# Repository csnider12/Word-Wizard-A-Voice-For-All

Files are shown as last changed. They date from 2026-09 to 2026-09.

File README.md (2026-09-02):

# 🪄 Word Wizard — A Voice For All

**A portable, NFC-based AAC (Augmentative and Alternative Communication) device that gives non-verbal individuals a fast, low-cost, and customizable way to communicate.**

> "Non-verbal individuals often rely on communication tools that are very limited and difficult to customize, as users often have different needs. Educators would benefit from a device that converts physical input to verbal communication that is portable and customizable."

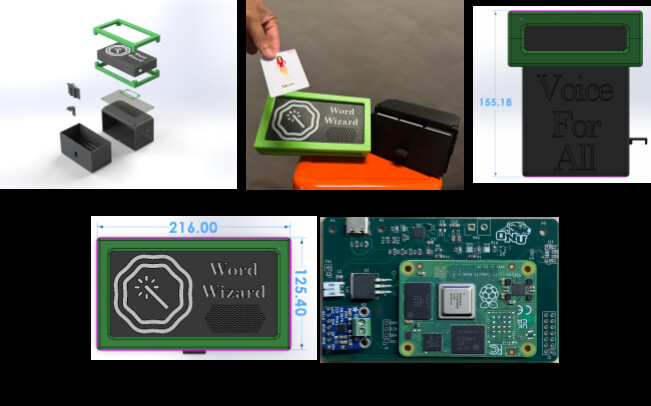
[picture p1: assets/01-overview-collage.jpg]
Word Wizard overview: CAD assembly, device in use, and internal electronics


---

## Table of Contents

- [Overview](#overview)
- [Features](#features)
- [How It Works](#how-it-works)
- [Hardware](#hardware)
- [Electronics & Firmware](#electronics--firmware)
- [Engineering Deep Dive: The PCB Fault](#engineering-deep-dive-the-pcb-fault)
- [Testing: Speaker Grille Optimization](#testing-speaker-grille-optimization)
- [Bill of Materials](#bill-of-materials)
- [Repo Structure](#repo-structure)
- [Design Documentation](#design-documentation)
- [Future Work](#future-work)
- [Broader Impacts](#broader-impacts)
- [Team](#team)
- [Acknowledgments](#acknowledgments)

---

## Overview

Word Wizard is a semester-long engineering project built to give non-verbal students, educators, and caregivers a simple, durable, and affordable alternative to expensive tablet-based AAC systems. A user taps a color-coded NFC communication card on the device, and Word Wizard speaks the corresponding word or phrase aloud through an onboard text-to-speech (TTS) engine.

The device is built around a **Raspberry Pi Compute Module 4** on a custom-designed PCB, an **NFC reader** for card input, a **Piper TTS engine** for multilingual speech output, and a fully 3D-printed enclosure with an integrated card storage drawer.

## Features

-  **NFC-based input** — tap a card, hear a word. No menus, no screens, no complex UI.
-  **Fitzgerald Key color coding** — cards are grouped by grammatical category (questions, actions, social words, people) using a widely recognized AAC standard.
-  **Multilingual TTS** — powered by the [Piper](https://github.com/rhasspy/piper) TTS engine, supporting multiple languages and dialects.
-  **USB-C rechargeable** — ≥30 Wh battery, no proprietary cables or disposable batteries.
-  **Fully customizable vocabulary** — any NFC-writable smartphone can reprogram a card in seconds.
-  **Durable, drop-tested enclosure** — TPU bumper rated for drops from ~3 ft onto hard flooring.
-  **Integrated card storage** — drawer system holds 40+ color-coded cards.
-  **Low-cost alternative** — significantly cheaper than tablet-based AAC solutions, and scalable for classroom/bulk deployment.

## How It Works

1. A teacher or parent programs an NFC card with a word or phrase using any NFC-write-capable smartphone.
2. The user taps the card on the device's NFC reader (marked by the wand logo).
3. A PN532 NFC reader (I2C) on the custom PCB reads the NDEF text record off the card.
4. The Raspberry Pi Compute Module 4 parses the NFC payload and passes it to the Piper TTS engine.
5. Audio is output through a Class-D mono amplifier and speaker, tuned to 60–65 dB (normal speech volume).

## Hardware

| Spec | Detail |
|---|---|
| Compute | Raspberry Pi Compute Module 4 |
| Input | PN532 NFC reader (I2C) |
| Audio | MAX98357A Class-D I2S amplifier + speaker |
| Power | 2S Li-Ion pack, BQ25886 charge management, USB-C input |
| Enclosure | PLA (case, drawer), TPU (bumper, gasket), cast acrylic (lid) |
| Manufacturing | FDM 3D printing (BambuLab A1) |
| Dimensions | 216.0 × 125.4 × 162.2 mm |
| Total weight | ~951 g |
| Battery life | ≥30 Wh |

The enclosure was fully modeled in SolidWorks — see [`design/`](design/) for CAD drawings of the case, drawer/slider assembly, and TPU bumpers, including standoffs for the PCB, speaker grille, charging port, switch port, and NFC reader slot.

## Electronics & Firmware

The custom PCB (`Word Wizard PCB`, designed in KiCad) integrates:

- **CM4 IO Board** — carrier board for the Compute Module 4
- **Power Management** — BQ25886 Li-Ion charger, 5V/5A LDO regulation, power-good and charge-status LEDs, USB-C PD-only input
- **High-Speed I/O** — USB OTG (micro-USB, for CM4 programming) with ESD protection
- **GPIO / DAC** — I2C to the PN532 NFC reader, PCM5122 I2S DAC feeding a MAX98357A audio amplifier

Firmware (C, see [`firmware/`](firmware/)) reads NDEF Text records off NTAG21x cards over I2C using [`pn532-lib`](https://github.com/soonuse/pn532-lib), parses the TLV/NDEF structure, and forwards the decoded text to the TTS pipeline.

```
Wiring (I2C, default):
  PN532 SDA -> RPi GPIO 2 (Pin 3)
  PN532 SCL -> RPi GPIO 3 (Pin 5)
  PN532 VCC -> 3.3V or 5V
  PN532 GND -> GND
```

## Problems: The PCB Fault

One of the most time-consuming parts of the project was tracking down an intermittent fault on the custom PCB. Code and hardware that worked fine on a jumper-wired development board began failing after being transferred to the custom board — the device would boot normally, then enter a boot loop roughly 20–30 seconds after a card was read.

**Diagnosis process:**

1. Ruled out power-supply issues by isolating each board on its own supply.
2. Put the PN532's I2C bus on an oscilloscope. The data line topped out at 3.1V instead of a full 3.3V logic high.

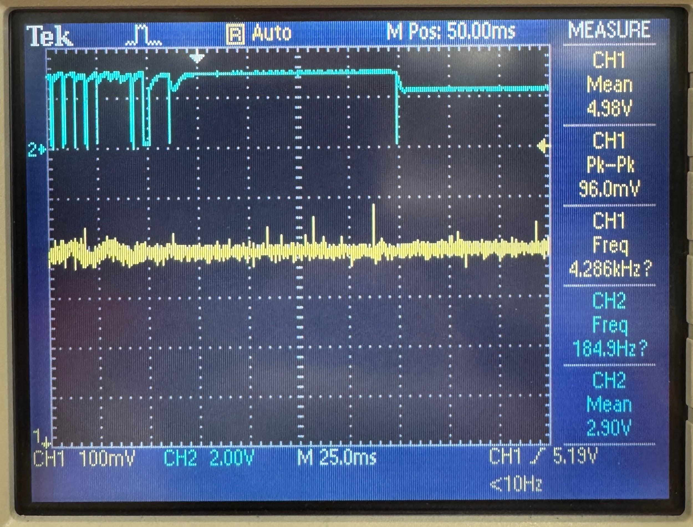
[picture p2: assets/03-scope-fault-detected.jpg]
Oscilloscope trace showing degraded I2C logic level
    

3. After ~20–30 seconds, the data line collapsed to 2.31V — indicating the board was hitting a thermal fail-safe and powering itself down.

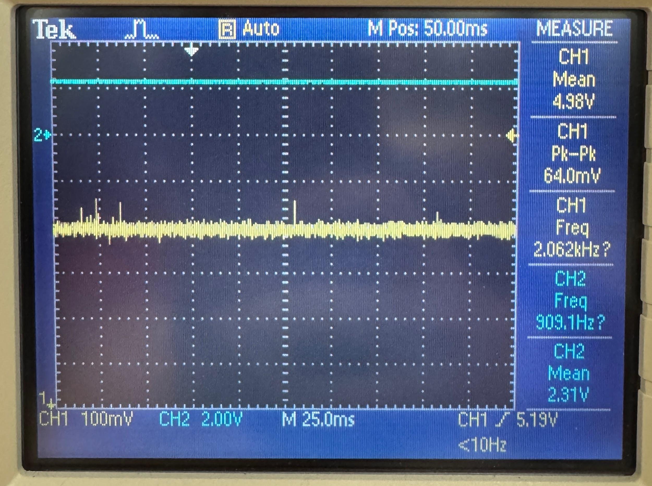
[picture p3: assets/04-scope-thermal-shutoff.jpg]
Oscilloscope trace showing CM4 thermal shutoff
    

4. Root cause: the CM4's **GPIO_VREF** pin — which must be hard-tied to 1.8V or 3.3V to set GPIO logic level — had been left floating on the custom board, settling at ~2.3V. External 3.3V pull-up resistors (added for the PN532) were fighting that incorrect reference, creating an extra thermal load that eventually tripped the CM4's thermal protection.
5. **Fix:** manually rewired GPIO_VREF directly to 3.3V using 39 AWG wire under a microscope — a delicate hand-soldering job on a Hirose board-to-board connector.

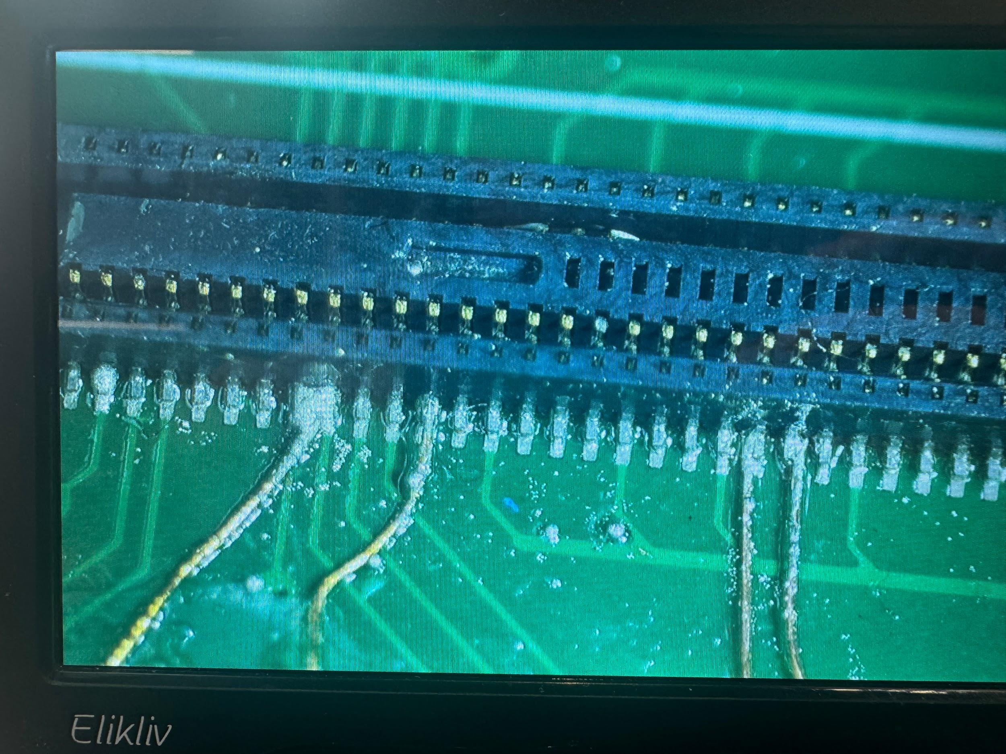
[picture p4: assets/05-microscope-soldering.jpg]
Microscope view of manual rework on the Hirose connector pins
    

6. Verified the fix back on the oscilloscope: clean rising/falling edges on both I2C lines, comfortably past the logic thresholds.

This was the single biggest lesson of the build: one unconnected reference pin caused hours of debugging, a reminder of how much value there is in double-checking datasheets and having a second set of eyes on a schematic before fabrication.

## Testing: Speaker Grille Optimization

To find the best trade-off between sound clarity and dust/debris resistance, the team 3D-printed six speaker grilles with hole diameters from 1.5mm to 4.0mm and measured sound pressure level (dB) at a fixed distance for three test phrases ("Why," "Please," "Stop").

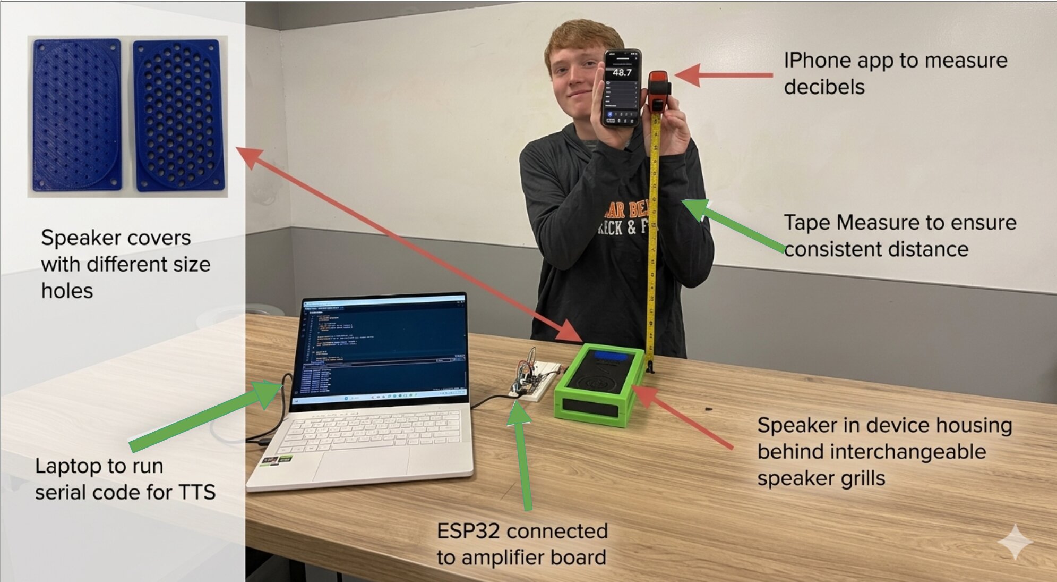
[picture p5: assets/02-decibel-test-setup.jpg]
Decibel testing setup with speaker, ESP32, amplifier, and sound level meter


**Result:** the **2.5mm hole diameter** produced the best average sound output (71.7 dB vs. 68.5 dB uncovered) while still offering meaningfully better debris resistance than larger holes. Full raw data and the test protocol are in [`testing/decibel-test-results.md`](testing/decibel-test-results.md).

## Bill of Materials

Full sourced BOM with vendor links and pricing is in [`bom/budget-tracker.md`](bom/budget-tracker.md). Total project spend: **~$205** (largely CM4/board, NFC reader, speaker, amp, and passives).

## Repo Structure

```
word-wizard/
├── README.md
├── firmware/            # NFC read + NDEF parsing (C)
├── hardware/            # KiCad schematics/PCB, connector notes
├── design/              # SolidWorks/CAD drawings, drawer & bumper parts
├── testing/             # Speaker grille dB test protocol + raw results
├── bom/                 # Sourced bill of materials
├── docs/                # Educator user manual, problem framing, broader impacts
└── assets/              # Photos and diagrams used in this README
```

> **Note:** this repo currently hosts the project write-up, CAD reference drawings, firmware, and PCB schematics consolidated from the team's final report. If you're setting this up as a fresh GitHub repo, drop your actual `.kicad_pro`/`.kicad_sch`, `.SLDPRT`/`.SLDASM`, and source files into the folders above alongside this README.

## Design Documentation

- [Educator Reference Manual](docs/user-manual.md) — setup, daily operation, charging, cleaning, troubleshooting
- [Problem Framing](docs/problem-framing.md) — stakeholders, research questions, assumptions, evaluation metrics
- [Broader Impacts](docs/broader-impacts.md) — People / Planet / Profit analysis with tradeoffs

## Future Work

- Move card access from a bottom drawer to a top-loading slot to reduce operating complexity for the primary user
- Merge the device and card-storage system into a single piece for easier management by teachers/parents
- Injection-molded silicone bumper (removable, phone-case style) instead of 3D-printed TPU, for easier cleaning and to escape FDM print constraints
- Switch the audio path from I2S to **SPI** to improve software/response speed
- Consolidate the electronics footprint to reduce overall device size and material use
- Standardize on common screws for all hardware to improve end-of-life disassembly and recyclability (balanced against tamper risk)

## Broader Impacts

| Category | Benefits | Risks / Tradeoffs |
|---|---|---|
| **People** | Shock-absorbent TPU bumper, USB-C (no proprietary cables), low-cognitive-load NFC tap input | Accessible screws are also a tamper/safety risk for young users; drawer adds a second part to manage |
| **Global/Cultural** | Fitzgerald Key is a recognized AAC standard; Piper TTS supports multiple languages/dialects | Color coding may not translate across cultures; NFC programming requires a smartphone |
| **Planet** | No laminate/print waste from reprogramming; modular hardware extends device life; rechargeable battery; recyclable ABS/TPU | PCB components are non-biodegradable; current manufacturing is energy-intensive |
| **Profit** | Lower cost than tablet AAC alternatives; scalable/modular for schools; costs drop with bulk orders | Long device lifespan reduces repeat business; SPI migration would add R&D cost |

Full stakeholder analysis and research log in [`docs/problem-framing.md`](docs/problem-framing.md).

## Team

Built by **Team 5**, Ohio Northern University — Foundations of Design II, 2026.

| Name | Focus Areas |
|---|---|
| Ethan D'Souza | Documentation, testing, broader impacts, electronics selection |
| Logan Frazer | CAD, NFC card programming, drawing annotation |
| Aiden McManis | Poster, scheduling/Gantt, presentation, drawer/slider design |
| Owen Willoby | Poster design, budget tracking, troubleshooting |
| Jeremiah Koenig | Final assembly, PCB population, presentation |
| Collin Snider | PCB design, diagnosis & rework, wiring/assembly |

## Acknowledgments

- Christina Teevan, Executive Director, Ashland Special Needs Ministry — early-stage user research
- Ohio Northern University Foundations of Design II course staff
- AI tools (Claude, Gemini, ChatGPT, GPAI) were used for problem framing, text refinement, and firmware assistance — see [`docs/ai-disclosure.md`](docs/ai-disclosure.md)

## License

Released under the [MIT License](LICENSE) — feel free to fork, build on, or adapt this project. Swap in a different license if your team/school has different preferences.

---

*Originally submitted as a final capstone report. Ported to GitHub as a project reference and portfolio piece.*

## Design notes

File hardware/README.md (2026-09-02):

# Hardware — Word Wizard PCB

Custom carrier/IO board for the Raspberry Pi Compute Module 4, designed in **KiCad 9.0.4**.

| Sheet | Contents |
|---|---|
| `CM4 IO Board` (top) | CM4 module footprint, mounting holes, sheet references |
| `CM4_GPIO` | 5x GPIO breakout, I2C (NFC reader), I2S audio, boot jumpers |
| `CM4_HighSpeed` | Micro-USB (CM4 programming) with ESD protection, USB OTG |
| `Power Management` | BQ25886 Li-Ion charger, USB-C power-only input, 5V/5A LDO, status LEDs |
| `DAC` (under CM4_GPIO) | PCM5122 I2S DAC → MAX98357A Class-D audio amplifier |

## Key design notes

- **Power path:** USB-C (power only) → BQ25886 charge management → 2S Li-Ion pack → LM1084-5.0 LDO for a clean 5V rail to electronics.
  - R2 (8kΩ) sets ~2.2A charge current (~0.4C for the battery)
  - R3 (150kΩ) sets 8.4V charging voltage
  - R4 (383Ω) sets ~2.9A max input current
  - R7/R9 (5.1kΩ on CC pins) configure 5V/3A charge negotiation over USB-C
- **NFC reader:** PN532, I2C interface, connected via the GPIO breakout sheet.
- **Audio:** PCM5122 I2S DAC feeding a MAX98357A mono Class-D amplifier (gain set by R1: 0Ω = left channel / 9dB gain).
- **Programming:** Micro-USB OTG port for flashing the CM4's eMMC, protected by a TPD4EUSB30 ESD array.

## ⚠️ Known erratum — GPIO_VREF must be tied, not left floating

On the first board revision, **GPIO_VREF (CM4 pin 78)** was left floating, which averaged to ~2.3V and caused the CM4 to enter a thermal fail-safe shutdown roughly 20–30 seconds after boot (see the [PCB fault deep-dive in the main README](../README.md#engineering-deep-dive-the-pcb-fault)). If you're laying out your own revision of this board, **hard-tie GPIO_VREF directly to 3.3V** in the schematic and layout — don't rely on external pull-ups alone.

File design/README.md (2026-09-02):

# Design — CAD & Mechanical

Above

## Assembly Overview

**Overall dimensions (L×W×H):** 216.00 × 125.40 × 162.18 mm
**Total weight:** ~951 g

| # | Part | Material | Weight (g) | Manufacturing |
|---|---|---|---|---|
| 1 | Drawer Box | PLA | 237 | FDM 3D printed |
| 2 | Drawer | PLA | 302 | FDM 3D printed, ~7h 52m print time |
| 3 | Slider | PLA | 3.55 | FDM 3D printed, ~11 min print time |
| 4 | Slider Guide | PLA | 9.58 | FDM 3D printed, ~23 min print time |
| 5 | Case | PLA | 170 | FDM 3D printed, ~3.75 hr print time (BambuLab A1) |
| 6 | Lid | Cast Acrylic | 118 | — |
| 7 | Speaker Gasket | TPU | 0.47 | FDM 3D printed |
| 8 | Bumper Bottom | TPU | 52.4 | FDM 3D printed, ~2.8 hr print time |
| 9 | Bumper Top | TPU | 58.2 | FDM 3D printed, ~2.9 hr print time |

**Misc. assembly hardware:** 4x M3×5mm screws + inserts, 4x M4×15mm screws + inserts, cyanoacrylate glue.

## Assembly Notes

- Insert the slider first, and lock it in place with the slider guide.
- Secure the speaker gasket between the speaker and casing before screwing the assembly together.
- Screw the acrylic lid to the case.
- Glue bumpers to the edges of the case (×2).
- The case includes 9x standoffs for the PCB, plus cutouts for the speaker grille, switch port, charging port, and NFC reader slot.
- All fillets on TPU bumper parts are 3mm.
- The drawer/slider system uses a gravity latch so the drawer can be lifted without requiring much dexterity — a deliberate accessibility choice for the primary stakeholder (the student/user).

See the [Future Work section of the main README](../README.md#future-work) for planned mechanical revisions (top-loading card access, injection-molded silicone bumper, single-piece device/storage design).

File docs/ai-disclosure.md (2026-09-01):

# Appendix: AI Disclosure

AI was used in problem framing, refining text, and programming the device. AI models used were Claude, Gemini, ChatGPT, and GPAI.

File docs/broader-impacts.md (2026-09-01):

# Appendix: Broader Impacts

| Category | Benefits | Risks and Tradeoffs |
|---|---|---|
| **People — Public Health, Safety & Welfare** | Shock-absorbent TPU bumper reduces injury risk when dropped or thrown. USB-C eliminates the need for proprietary cables. Simple NFC tap input reduces cognitive load for the intended user. | Easy-access screws for repair can be a safety hazard to young/curious individuals. TPU bumper increases overall device footprint. Drawer system requires the device to have two separate parts to manage. |
| **People — Global / Cultural Factors** | Color-coded Fitzgerald Key is a widely recognized AAC standard. The Piper TTS model allows the system to output multiple languages and dialects. | Color coding may not transfer across different cultures. NFC programming requires a smartphone or other proprietary device. |
| **Planet — Environmental** | Programmable cards reduce the need for laminate/print waste. Modular electronic hardware extends device life, reducing waste. Rechargeable battery reduces single-use waste. ABS and TPU are recyclable materials. | Components like the PCB are non-biodegradable. Current manufacturing process is energy-intensive. |
| **Profit — Economic** | Lower cost than tablet-based AAC alternatives. Design is easily scalable and modular for large-quantity school/care-center needs. Electronics are easy to fabricate, and per-unit price drops with bulk orders. | Switching to SPI protocol would require additional R&D man-hours, raising costs. Long product lifespan reduces repeat business unless a compelling updated product is released. |

## Ecodesign Strategies Considered

- **Optimize end-of-life system** by making all hardware components accessible via common screws, increasing ease of disassembly and recyclability — tradeoff: could tempt users to tinker and harm device functionality.
- **Optimize initial lifetime** by reducing the number of soldered-to-connector parts, easing repairability — tradeoff: could reduce reliability if parts get jostled loose during use.
- **Reduce materials** by further consolidating the electronics footprint to shrink the device and reduce material use — tradeoff: could increase electronics complexity and cost.

The team believes there is a viable middle ground across these strategies that balances repairability, reliability, and cost.

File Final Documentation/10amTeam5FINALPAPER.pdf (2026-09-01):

# Word Wizard

“Non-verbal individuals often rely on communication tools that are very limited and difficult to

customize, as users often have different needs. Educators would benefit from a device that

converts physical input to verbal communication that is portable and customizable.”

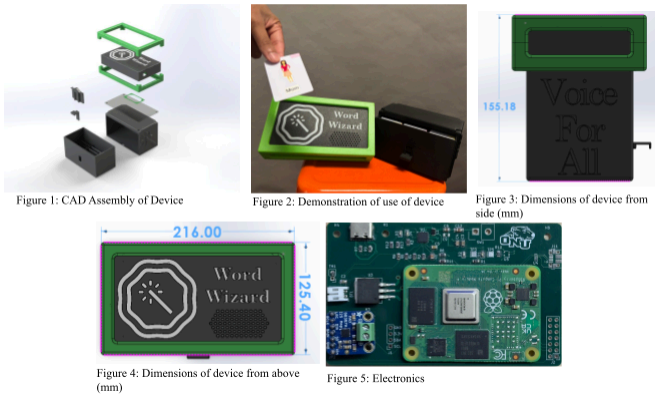
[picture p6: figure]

# Next Steps

While this design was extensively researched and revised over the course of the semester, our team recognized several features that could still be improved given we had more time. While our current storage system is innovative and easy to navigate, we believe the system could be improved by making the cards accessible from the top of the box rather than a drawer system to lower the complexity of operating the system for our primary stakeholder, the user. We also presume that making the device and the card system one piece would improve the manageability of Word Wizard for teachers and parents. Additionally we hope that in the future the bumper could be injection molded silicone so that we are not limited to 3-D printing capabilities. This is so we can make the bumper removable, similar to a phone case to improve the cleanability of the device. Finally we would implement an SPI communication protocol rather than the I2S protocol we currently use to optimize software speed for the device. These changes would help us compete in the global market more effectively and provide the best overall product for all stakeholders.

There are many ecodesign strategies we could employ in the further development of our product. We could optimize the end of life system by making all the hardware components accessible by common screws. This is so that we can increase the ease of disassembly and recyclability of the various different components. While this will be good for properly recycling components at end of life, it could tempt users to tinker and harm device functionality. Additionally we could optimize the initial lifetime by reducing the amount of soldered parts to connectors. While this makes repairability easier it could harm the reliability of the product as parts could be jostled loose during use. This is so that electronic parts can be easily swapped out to increase the lifespan of the device. Lastly we could further the reduction of materials by finding ways to further consolidate the footprint of the electronics. This will allow us to shrink the size of the device, reducing the necessary material required to fabricate all related parts. While this could reduce the footprint of the electronics, it could increase the complexity of the electronics further driving up costs. While these ecodesign strategies have pros and cons, we believe that there is a middle ground that makes these aspirations viable.

# Broader Impacts

Table 1: Broader Impacts

| Benefit | Risks and Tradeoffs
People - Public Health, Safety & Welfare | - Utilizing a shock absorbent TPU bumper reduces injury risk when dropped or thrown - USB - C eliminates the need for proprietary application specific cables - Simple NFC tap input reduces cognitive load for the intended user | - Easy to access screws for easy repair can be a a safety hazard to young and curious individuals - TPU bumper increases overall footprint of device - Drawer system requires device to have two separate parts to manage
People - Global / Cultural Factors | - Color coded Fitzgerald Key is a widely recognized AAC standard - utilizing Piper TTS model allows the system to output multiple languages and dialects | - color coding may not transfer across different cultures - NFC programming requires a smartphone or other proprietary device
Planet - Environmental | - programmable reduces need for laminate and print waste - Modular electronic hardware allows for extended life of device, reducing waste - Rechargeable battery reduces single-use waste - ABS and TPU are recyclable materials | - Various electrical components like the PCB are non-biodegradable - Current manufacturing process is very energy intensive
Profit - Economic | - Lower cost than tablet alternative AAC’s - Design is easily scalable and modular to accommodate large quantity needs for schools or care centers - Electronics are easy to fabricate and price gets lower as the bulk of the order increases | - a switch to SPI protocol would require further man-hours driving up our R&D costs - Our product has a long lifespan which will reduce our repeat business unless we come out with an updated more enticing product.

# Appendix 1: Problem Framing

Overview: Problem Framing Documentation For FoD2 Semester Project ‘Word Wizard’

Broader Impacts:
1. People - Inclusion and Accessibility to reduce stigma around disability
2. Planet - Long-lasting and purpose built solution allows for less material waste and power consumption
3. Profit - Lower cost and scalable solution compared to existing assistive technologies

Stakeholders:

Table 2: Stakeholders

| Stakeholder | Impact | Design decision considerations
1 | Student | Usability, Comfort, Reliability | Safer casing, minimal simplistic inputs
2 | Teachers | Integration and Manageability | Small, rechargeable, minimal design, with clear colors for locatability
3 | Administrators | Budget and Policy Compliance | Low-tech design, Cost less than common alternatives (Tablet, or other repurposed smart device)
4 | Parents | Independence and Safety | Soft outer casing, simplistic usability for a wide age range

Research:

Table 3: Preliminary Research

Prompting
Question
Source | Specific information gathered | What will you do with this info?
| DR1
1 | How tall are classroom desks and tables? | [1] 24”-30” | | This data will influence our durability benchmarks.
2 | How can we smooth 3D prints? | [2, 3] | ABS can be smoothed with acetone, TPU can be smoothed with DMSO | Consider solvent smoothing for the surface finish of 3D printed parts

3 | What is the most common consumer charging cable? | [4] | USB Type-C is “Common on modern laptops, smartphones, and game consoles. [It] is the new industry standard.” | We will use a USB-C port for power input
4 | What kind of 3D printing filament is the most durable? | [5] | ABS has a higher impact resistance than both PLA and PETG but it has worse printability. | ABS will be the preferred filament as it is the strongest and we will have to be more careful when printing with it.
5 | Why use NFC tags instead of anything else for Voice recording? | [6] | NFC tags offer an easy, touch-based way to play, record, or update audio, making them highly accessible for tasks like labeling objects for the visually impaired or creating personalized voice messages without using complex menus. | We will use NFC tags for easy use and easy updating
6 | What are the issues with paper communication cards? | Christina Teevan, Ashland Special Needs Ministry Executive Director | The commonly used paper cards are not durable, difficult to organize, and take concentration by both parties to communicate. | We will make a device to combine physical communication cards and text-to-speech communication devices.

DR2

1

What is an
effective dB level
for sufficient
communication
and how will our
enclosure affect
that?

[1]

- Target output at listener: 60-65 dB
- Upper practical range:
65-70 dB (if classroom
noise is higher)

This aligns with:

- Normal speech = 60 dB
- Slightly raised voice =
65–70 dB

Aim for a noise range between 60 -65 Decibels

2

How do educators
currently store,
organize, and
manage
communication
cards in classroom
environments?

[2]

Bins and Binder Pockets -
Educators typically use baseball card organizers to track specific cards, and store larger amounts of cards in small storage bins

Develop a system that blends these two tracking systems. I.e. organized drawer

DR 3

1 | How can we reduce rattling of the speaker when mounted in the casing? | [1] | “When a speaker is mounted behind a cover, the sealing between the speaker and the surface dictate the Sound Pressure Level”[1] Air leaking out the speakers rim | Add a sort of gasket to seal the speaker
2 | How can we further make cards easier to organize? | [2] | - Augmentative and Alternative Communication(AAC) systems [2] - Fitzgerald Key: Assigns colors to differentiate various grammatical categories [2] - Color coded designs require less cognitive load [3] | Color code the cards to better organize and track them

Assumptions:
1. Because classroom desks and tables are typically 24”-30” tall [1], we assume accidental drops from approximately 3 feet onto hard flooring are likely. Therefore, we will design the enclosure to withstand at least a 3 foot drop without functional failure.
2. Because some non-verbal individuals may also experience visual processing challenges, we assume high-contrast visual cues will improve usability. Therefore, we will use contrasting colors and clear iconography to indicate interaction zones.
3. Based on classroom environments where many interactable objects are used simultaneously, we assume communication cards may frequently be misplaced. Therefore, we will research and integrate a dedicated card storage or tethering solution.
4. Based on hygiene practices in schools and therapy settings, we assume the device will require frequent surface cleaning. Therefore, we will select enclosure materials (ABS/TPU/PLA) that tolerate repeated wiping without degradation. It also may be necessary to seal surface pores to decrease bacterial buildup.
5. Because USB-C charging cables are commonly included with consumer electronics [4] and are easily purchasable, we assume that the users will have access to these cables more readily than other types. Therefore, we will include a USB-C port for power input.

Design Specifications:
Table 4: Evaluation Metric
| Evaluation Metric | Qty. to Measure | Units | Objective | Prototype Result
1 | Battery Life | Both | Watt-Hour (Wh) | ≥ 30 Watt-hours | Utilize a rechargeable battery that still accounts for safety
2 | Boot Time | EM | Seconds (s) | minimize | Optimize hardware utilizing a compute module
3 | Response Time | EM | Seconds (s) | minimize | Optimize hardware utilizing a compute module
4 | Sound Level | EM | Decibels (dB) | ≥ 60 | Functionally test different speaker grills for housing.
5 | Portability | EM | grams(g) | minimize | Minimized unnecessary additional cables and hardware to make device as transportable as possible
6. | Variability of Word List | C | # of cards | ≥ 30 | Diversified vocabulary so device can be versatile in many scenarios
7. | Customizability of Word List | EM | # of ways to change each card | maximize | Cards can be changed on a need to need basis very easily through a simple smartphone

# Appendix 2: Test Results

Test Title: Decibel Output Testing for Variable Speaker Holes

Purpose: To determine the best speaker cover to ensure the optimal sound clarity and quality determined by decibel levels.

Equipment:
- Speaker
- Microcontroller
- Amplifier
- Speaker covers (6 covers)
- Sound Level Meter
- Tape Measure
- Means to record data

Variables:

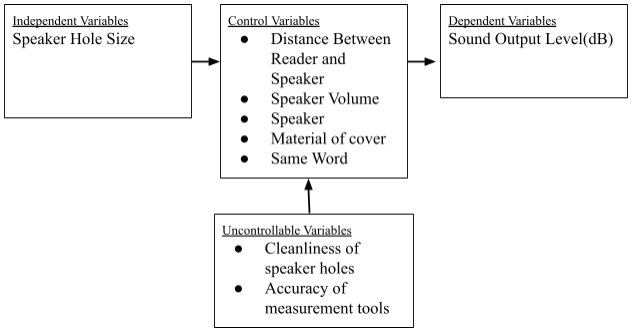
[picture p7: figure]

Experimental Setup:

Figure 6: Setup to test audio loss due to diameter of holes

Figures 7-9: CAD renderings for varying speaker cover hole diameters (1.5mm, 2.5mm, 3.5mm)

Procedure:
1. Gather all materials.
2. Place materials on a table that is cleared and ready for the test.
3. Hook up the speaker to the amplifier + microcontroller apparatus.
4. Cover speaker with speaker cover
5. Hold sound level reader at ear level
a. Speaker should be oriented towards you, still on the table
6. Use the sound level reader to collect data from the speaker output.
7. Output text to speech word from the speaker.
8. Repeat steps 4 through 6, changing / adding the speaker cover of varying hole diameters.
9. Write down results in the data table.
10. Write down any observations collected during the test.

Quantitative Results:
Table 5: Table to collect effective decibels across three tests at different amounts of obstruction

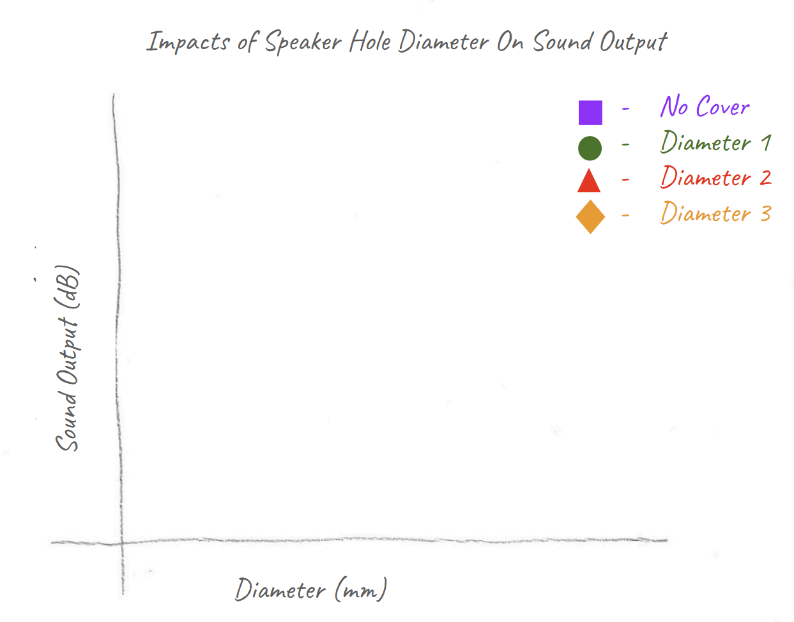
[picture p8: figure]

Figure 10: Scatterchart to compare effective decibels at different diameters of holes

Decibels (dB) | Control (no cover) | Hole Diameters (mm)
D1 | D2 | D3
Run 1
Run 2
Run 3
Average

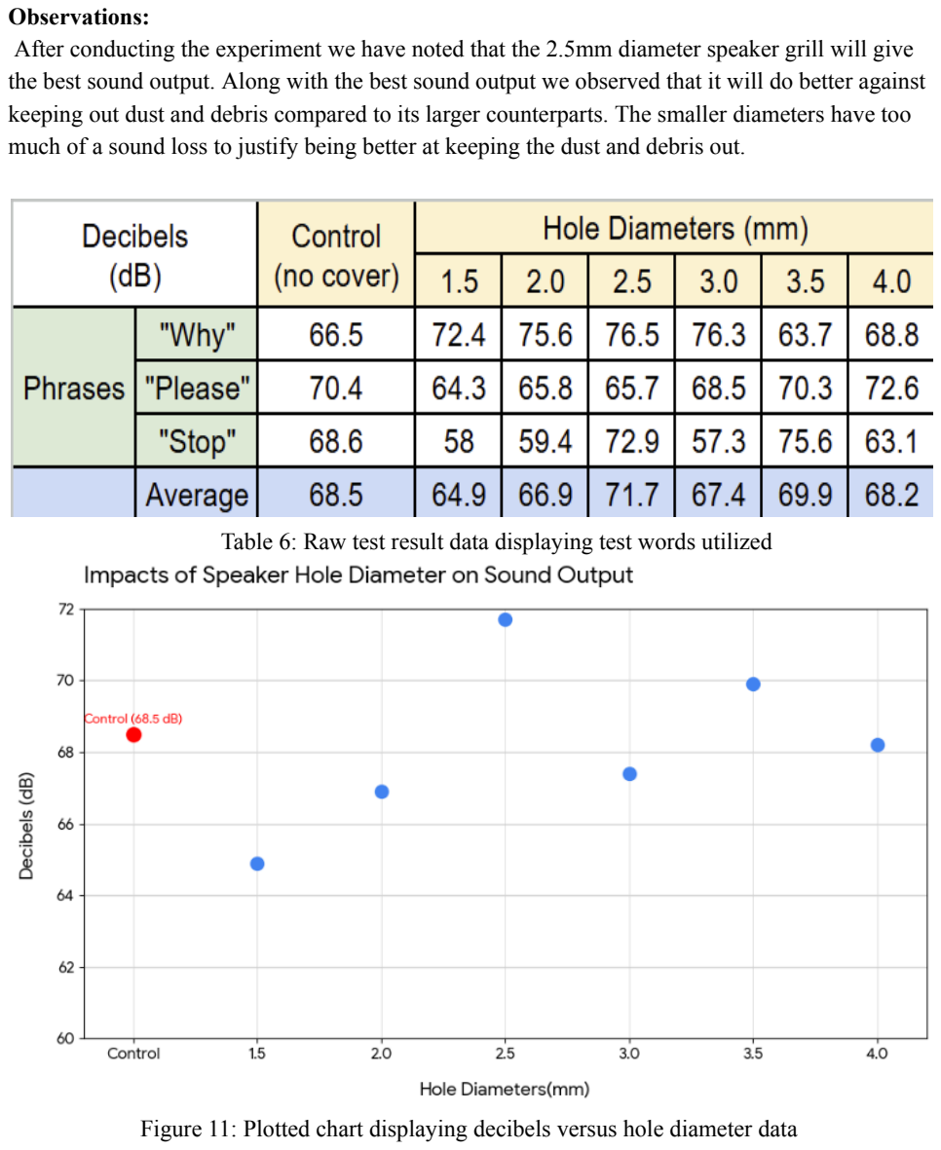
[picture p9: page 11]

Observations:
After conducting the experiment we have noted that the 2.5mm diameter speaker grill will give the best sound output. Along with the best sound output we observed that it will do better against keeping out dust and debris compared to its larger counterparts. The smaller diameters have too much of a sound loss to justify being better at keeping the dust and debris out.

Table 6: Raw test result data displaying test words utilized

Figure 11: Plotted chart displaying decibels versus hole diameter data

Picture:

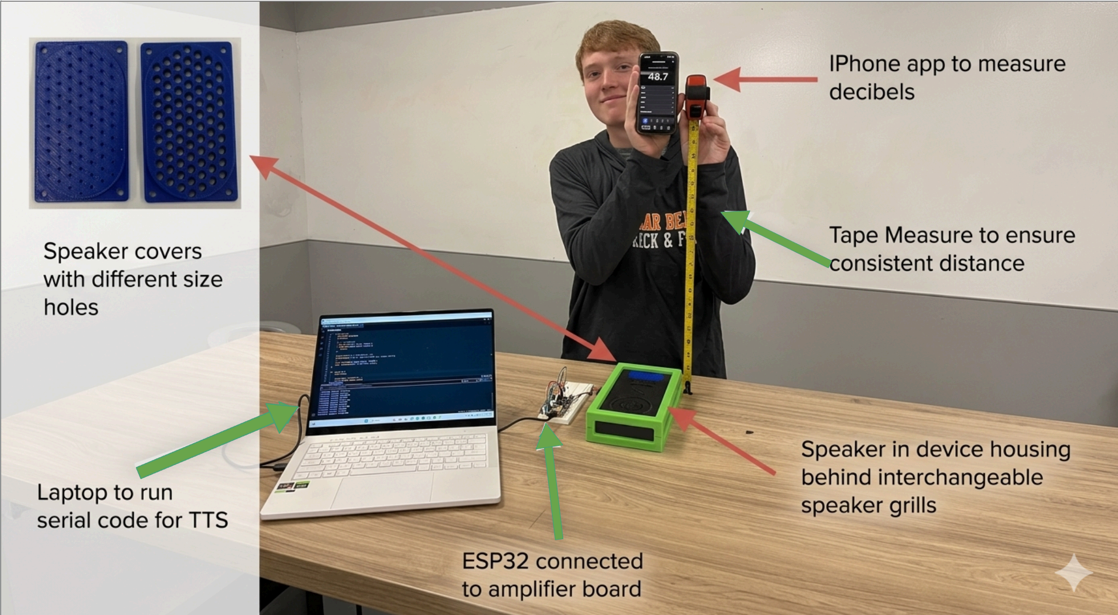
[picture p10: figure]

Conducted by: Ethan D’souza, Owen Willoby, Jeremiah Koenig, Aiden McManis

Date test conducted: 4/9/26

# Appendix 3: Design Details

B | B

2

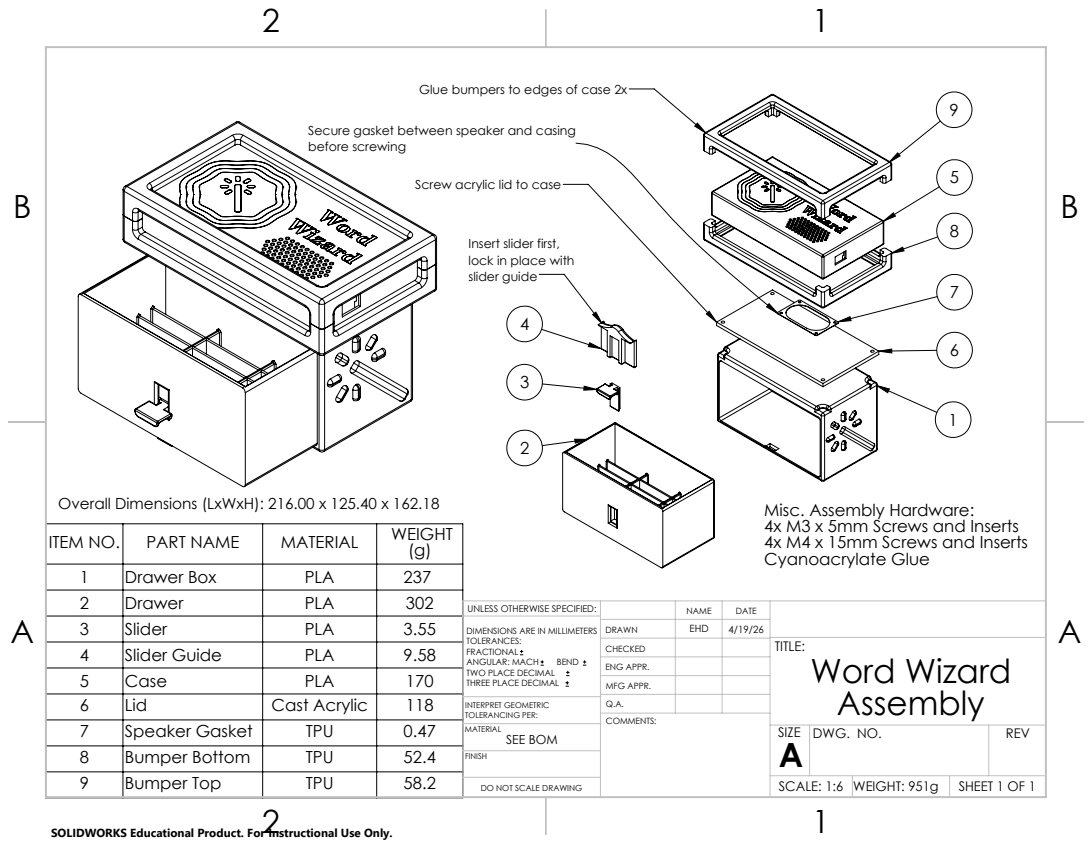
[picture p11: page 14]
SEE BOM; DWG. NO.; REV; SIZE; COMMENTS:; FINISH; MATERIAL

Glue bumpers to edges of case 2x

Secure gasket between speaker and casing
before screwing

Screw acrylic lid to case

Insert slider first,
lock in place with
slider guide

Overall Dimensions (LxWxH): 216.00 x 125.40 x 162.18

Misc. Assembly Hardware:
4x M3 x 5mm Screws and Inserts
4x M4 x 15mm Screws and Inserts
Cyanoacrylate Glue

ITEM NO. | PART NAME | MATERIAL | WEIGHT (g)
1 | Drawer Box | PLA | 237
2 | Drawer | PLA | 302
3 | Slider | PLA | 3.55 | DIMENSIONS ARE IN MILLIMETERS TOLERANCES: FRACTIONAL ANGULAR: MACH BEND TWO PLACE DECIMAL THREE PLACE DECIMAL | DRAWN | EHD | 4/19/26
4 | Slider Guide | PLA | 9.58 | | CHECKED | | | TITLE: Word Wizard Assembly
5 | Case | PLA | 170
6 | Lid | Cast Acrylic | 118 | INTERPRET GEOMETRIC TOLERANCING PER: | Q.A.
7 | Speaker Gasket | TPU | 0.47
8 | Bumper Bottom | TPU | 52.4
9 | Bumper Top | TPU | 58.2

UNLESS OTHERWISE SPECIFIED: | | NAME | DATE

ENG APPR.
MFG APPR.

DO NOT SCALE DRAWING | SCALE: 1:6 | WEIGHT: 951g | SHEET 1 OF 1

SOLIDWORKS Educational Product. For Instructional Use Only.

B | B

2

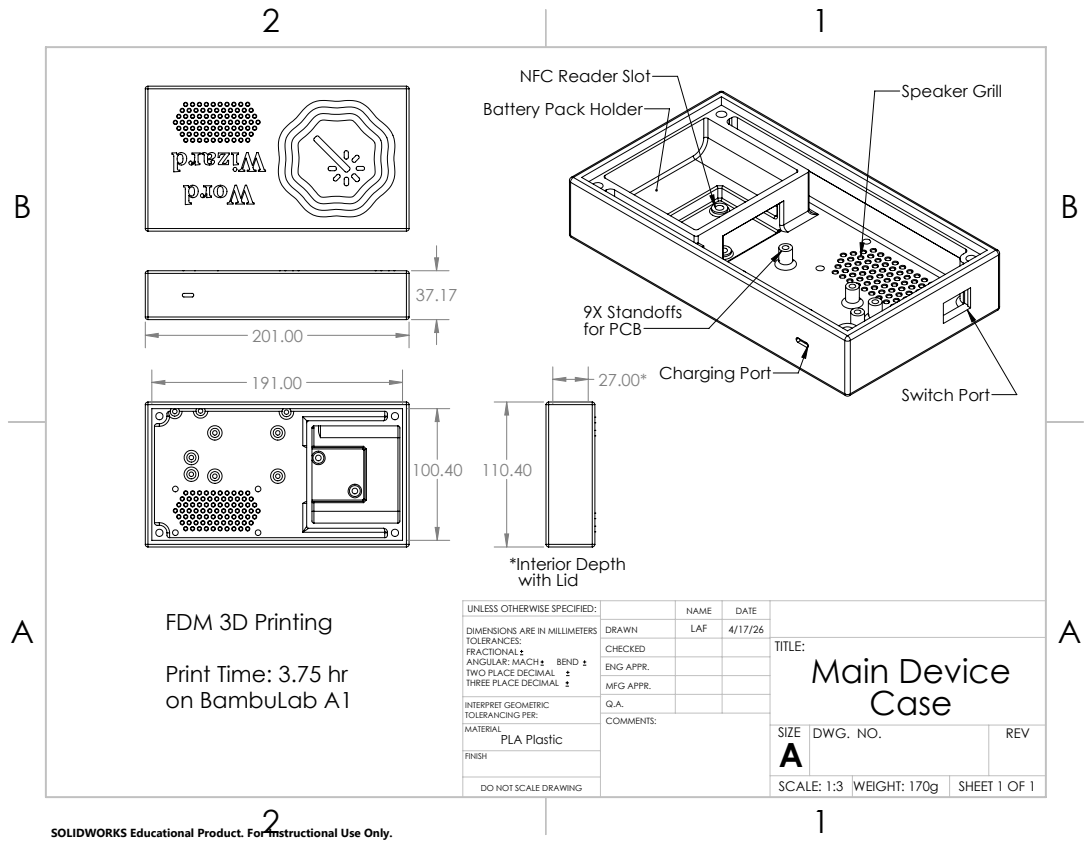
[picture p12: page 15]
9X Standoffs for PCB; Speaker Grill; Switch Port; Charging Port; *Interior Depth with Lid; PLA Plastic; DO NOT SCALE DRAWING; SHEET 1 OF 1; SCALE: 1:3; WEIGHT: 170g; DWG. NO.; REV; SIZE; COMMENTS:; FINISH; MATERIAL

NFC Reader Slot
Battery Pack Holder

UNLESS OTHERWISE SPECIFIED: | | NAME | DATE
DIMENSIONS ARE IN MILLIMETERS TOLERANCES: FRACTIONAL ANGULAR: MACH BEND TWO PLACE DECIMAL THREE PLACE DECIMAL | DRAWN | LAF | 4/17/26

FDM 3D Printing
Print Time: 3.75 hr
on BambuLab A1

CHECKED | | | TITLE: Main Device Case

ENG APPR.
MFG APPR.

INTERPRET GEOMETRIC TOLERANCING PER: | Q.A.

SOLIDWORKS Educational Product. For Instructional Use Only.

B | B

2

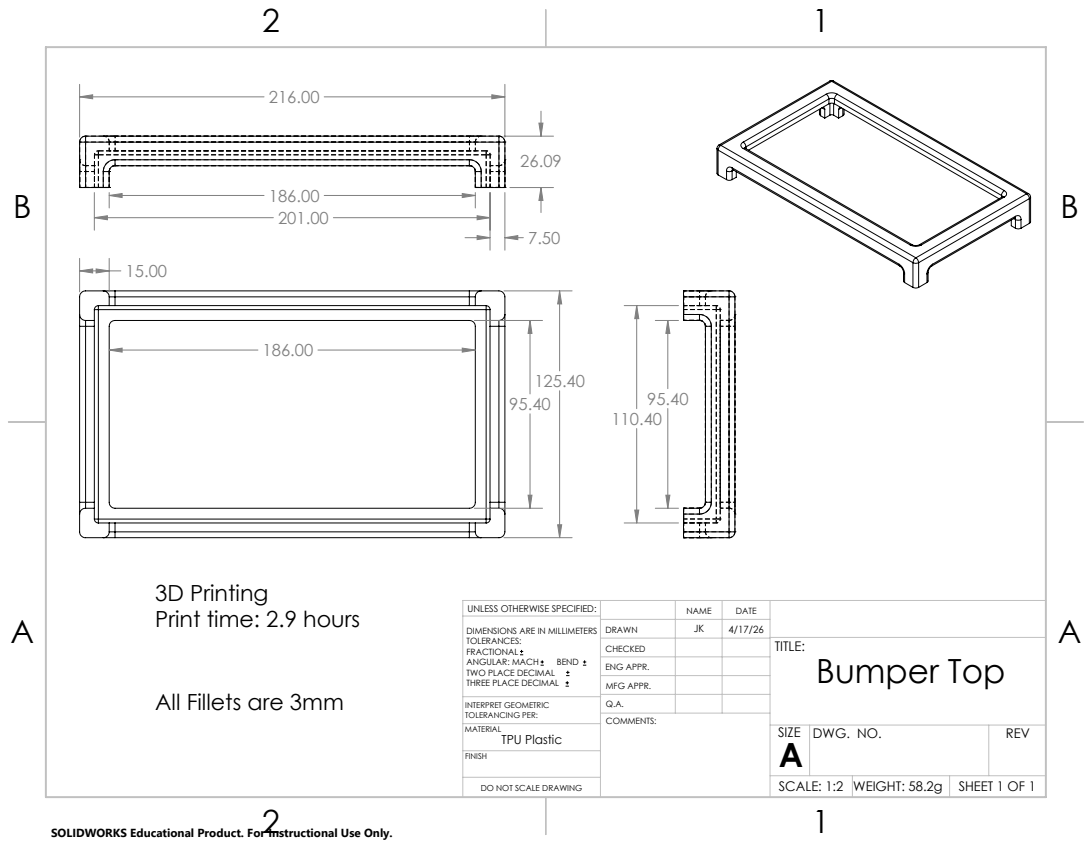
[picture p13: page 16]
TPU Plastic; DO NOT SCALE DRAWING; SHEET 1 OF 1; SCALE: 1:2; WEIGHT: 58.2g; DWG. NO.; REV; SIZE; COMMENTS:; FINISH; MATERIAL

3D Printing
Print time: 2.9 hours

UNLESS OTHERWISE SPECIFIED: | | NAME | DATE
DIMENSIONS ARE IN MILLIMETERS TOLERANCES: FRACTIONAL ANGULAR: MACH BEND TWO PLACE DECIMAL THREE PLACE DECIMAL | DRAWN | JK | 4/17/26

CHECKED | | | TITLE: Bumper Top

ENG APPR.
MFG APPR.

All Fillets are 3mm

INTERPRET GEOMETRIC TOLERANCING PER: | Q.A.

SOLIDWORKS Educational Product. For Instructional Use Only.

B | B

2

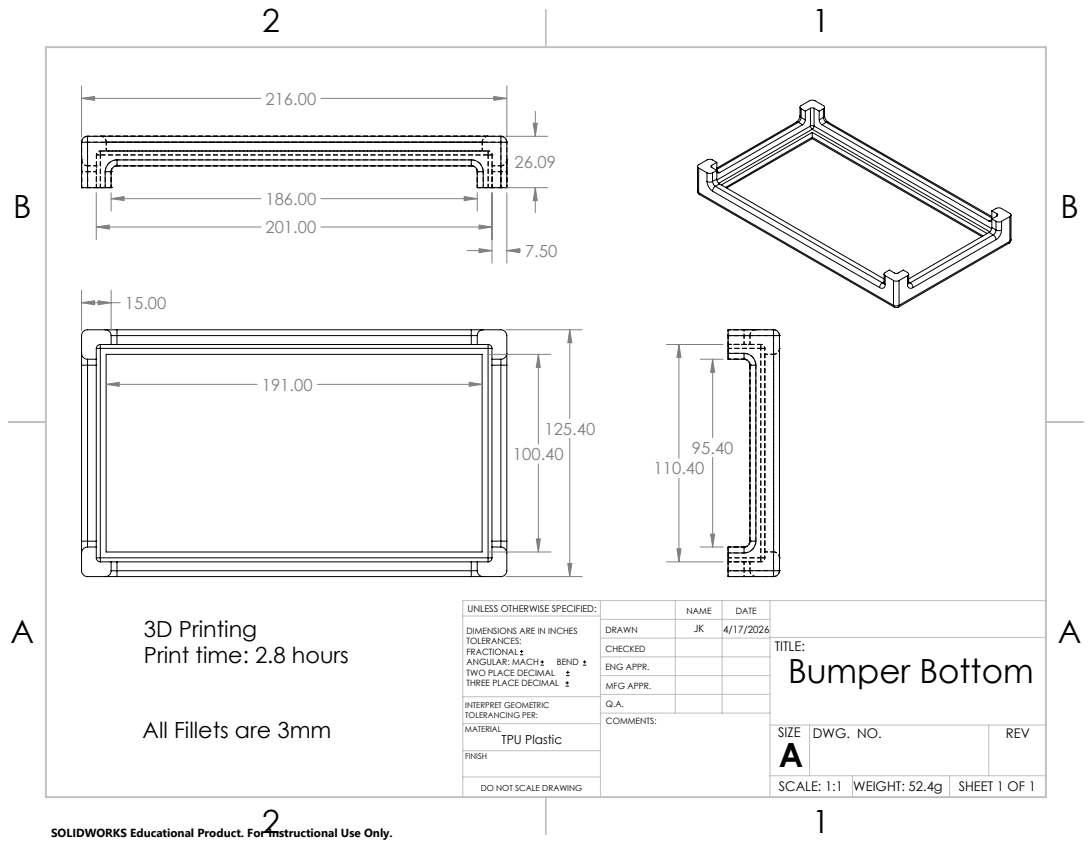
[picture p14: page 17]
TPU Plastic; DO NOT SCALE DRAWING; SHEET 1 OF 1; SCALE: 1:1; WEIGHT: 52.4g; DWG. NO.; REV; SIZE; COMMENTS:; FINISH; MATERIAL

UNLESS OTHERWISE SPECIFIED: | | NAME | DATE
DIMENSIONS ARE IN INCHES TOLERANCES: FRACTIONAL ANGULAR: MACH BEND TWO PLACE DECIMAL THREE PLACE DECIMAL | DRAWN | JK | 4/17/2026

3D Printing
Print time: 2.8 hours

CHECKED | | | TITLE: Bumper Bottom

ENG APPR.
MFG APPR.

INTERPRET GEOMETRIC TOLERANCING PER: | Q.A.

All Fillets are 3mm

SOLIDWORKS Educational Product. For Instructional Use Only.

B | B

2

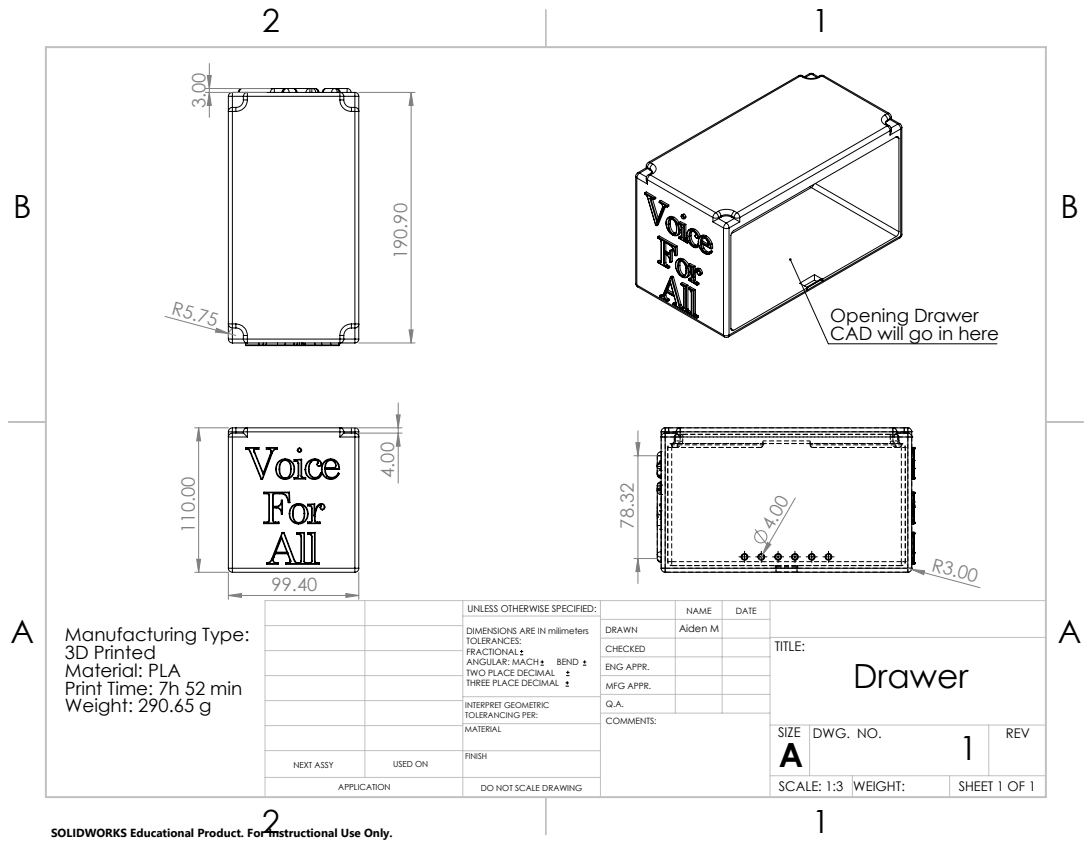
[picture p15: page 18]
COMMENTS:

Opening Drawer
CAD will go in here

UNLESS OTHERWISE SPECIFIED: | | NAME | DATE
DIMENSIONS ARE IN milimeters TOLERANCES: FRACTIONAL ANGULAR: MACH BEND TWO PLACE DECIMAL THREE PLACE DECIMAL | DRAWN | Aiden M

Manufacturing Type:
3D Printed
Material: PLA
Print Time: 7h 52 min
Weight: 290.65 g

CHECKED | | | TITLE: Drawer

ENG APPR.
MFG APPR.

INTERPRET GEOMETRIC TOLERANCING PER: | Q.A.
MATERIAL | | SIZE A | DWG. NO. 1 | REV

NEXT ASSY | USED ON | FINISH

APPLICATION | DO NOT SCALE DRAWING | | SCALE: 1:3 | WEIGHT: | SHEET 1 OF 1

SOLIDWORKS Educational Product. For Instructional Use Only.

174.00

## Scale - 1:3

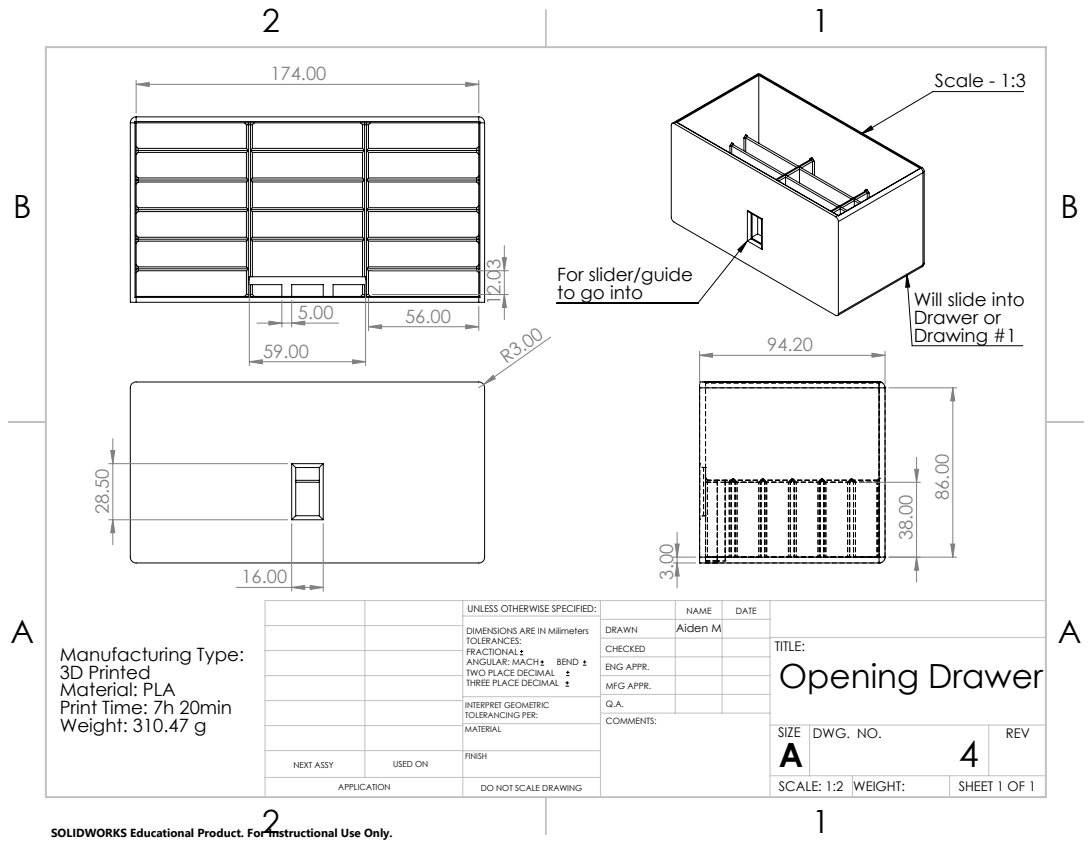
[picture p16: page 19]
to go into; Will slide into; Drawer or Drawing #1; COMMENTS:; Manufacturing Type: 3D Printed Material: PLA Print Time: 7h 20min Weight: 310.47 g

For slider/guide

UNLESS OTHERWISE SPECIFIED: | | NAME | DATE
DIMENSIONS ARE IN Milimeters TOLERANCES: FRACTIONAL ANGULAR: MACH BEND TWO PLACE DECIMAL THREE PLACE DECIMAL | DRAWN | Aiden M

CHECKED | | | TITLE: Opening Drawer

ENG APPR.
MFG APPR.

INTERPRET GEOMETRIC TOLERANCING PER: | Q.A.

NEXT ASSY | USED ON | MATERIAL | | SIZE A | DWG. NO. 4 | REV

FINISH

APPLICATION | DO NOT SCALE DRAWING | | SCALE: 1:2 | WEIGHT: | SHEET 1 OF 1

SOLIDWORKS Educational Product. For Instructional Use Only.

11.50

## Main design change

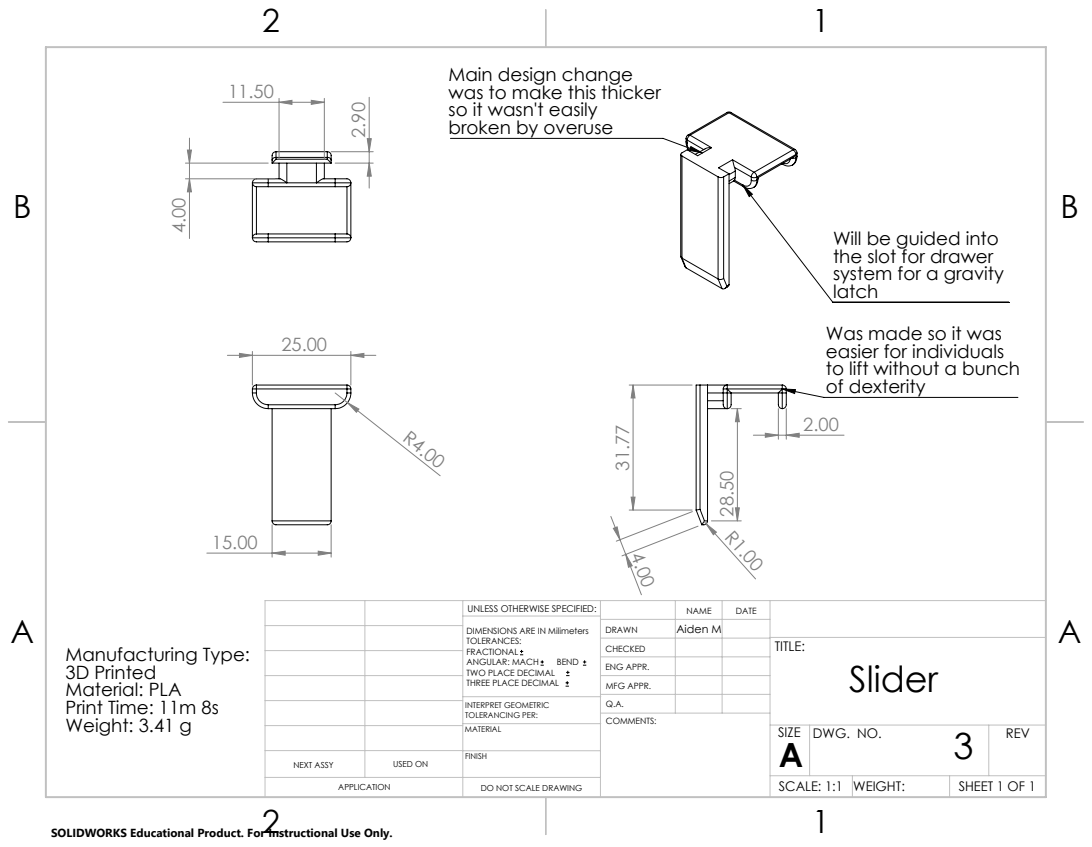
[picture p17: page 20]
COMMENTS:; Manufacturing Type: 3D Printed Material: PLA Print Time: 11m 8s Weight: 3.41 g

was to make this thicker
so it wasn't easily
broken by overuse

Will be guided into
the slot for drawer
system for a gravity
latch
Was made so it was
easier for individuals
to lift without a bunch
of dexterity

UNLESS OTHERWISE SPECIFIED: | | NAME | DATE
DIMENSIONS ARE IN Milimeters TOLERANCES: FRACTIONAL ANGULAR: MACH BEND TWO PLACE DECIMAL THREE PLACE DECIMAL | DRAWN | Aiden M
CHECKED | | | TITLE: Slider

ENG APPR.
MFG APPR.

INTERPRET GEOMETRIC TOLERANCING PER: | Q.A.
MATERIAL | | SIZE A | DWG. NO. 3 | REV

NEXT ASSY | USED ON | FINISH

APPLICATION | DO NOT SCALE DRAWING | | SCALE: 1:1 | WEIGHT: | SHEET 1 OF 1

SOLIDWORKS Educational Product. For Instructional Use Only.

B | B

2

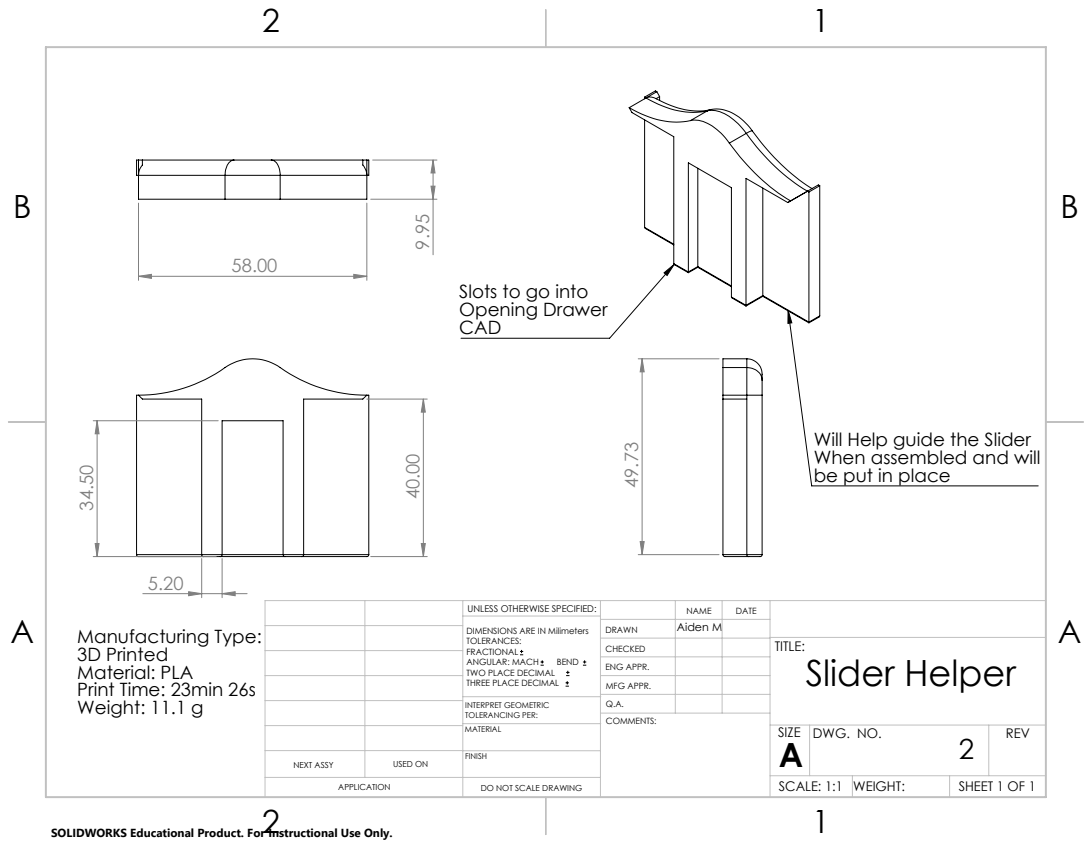
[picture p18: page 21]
COMMENTS:; Manufacturing Type: 3D Printed Material: PLA Print Time: 23min 26s Weight: 11.1 g

Slots to go into
Opening Drawer
CAD

Will Help guide the Slider
When assembled and will
be put in place

UNLESS OTHERWISE SPECIFIED: | | NAME | DATE
DIMENSIONS ARE IN Milimeters TOLERANCES: FRACTIONAL ANGULAR: MACH BEND TWO PLACE DECIMAL THREE PLACE DECIMAL | DRAWN | Aiden M
CHECKED | | | TITLE: Slider Helper

ENG APPR.
MFG APPR.

INTERPRET GEOMETRIC TOLERANCING PER: | Q.A.
MATERIAL | | SIZE A | DWG. NO. 2 | REV

NEXT ASSY | USED ON | FINISH

APPLICATION | DO NOT SCALE DRAWING | | SCALE: 1:1 | WEIGHT: | SHEET 1 OF 1

SOLIDWORKS Educational Product. For Instructional Use Only.

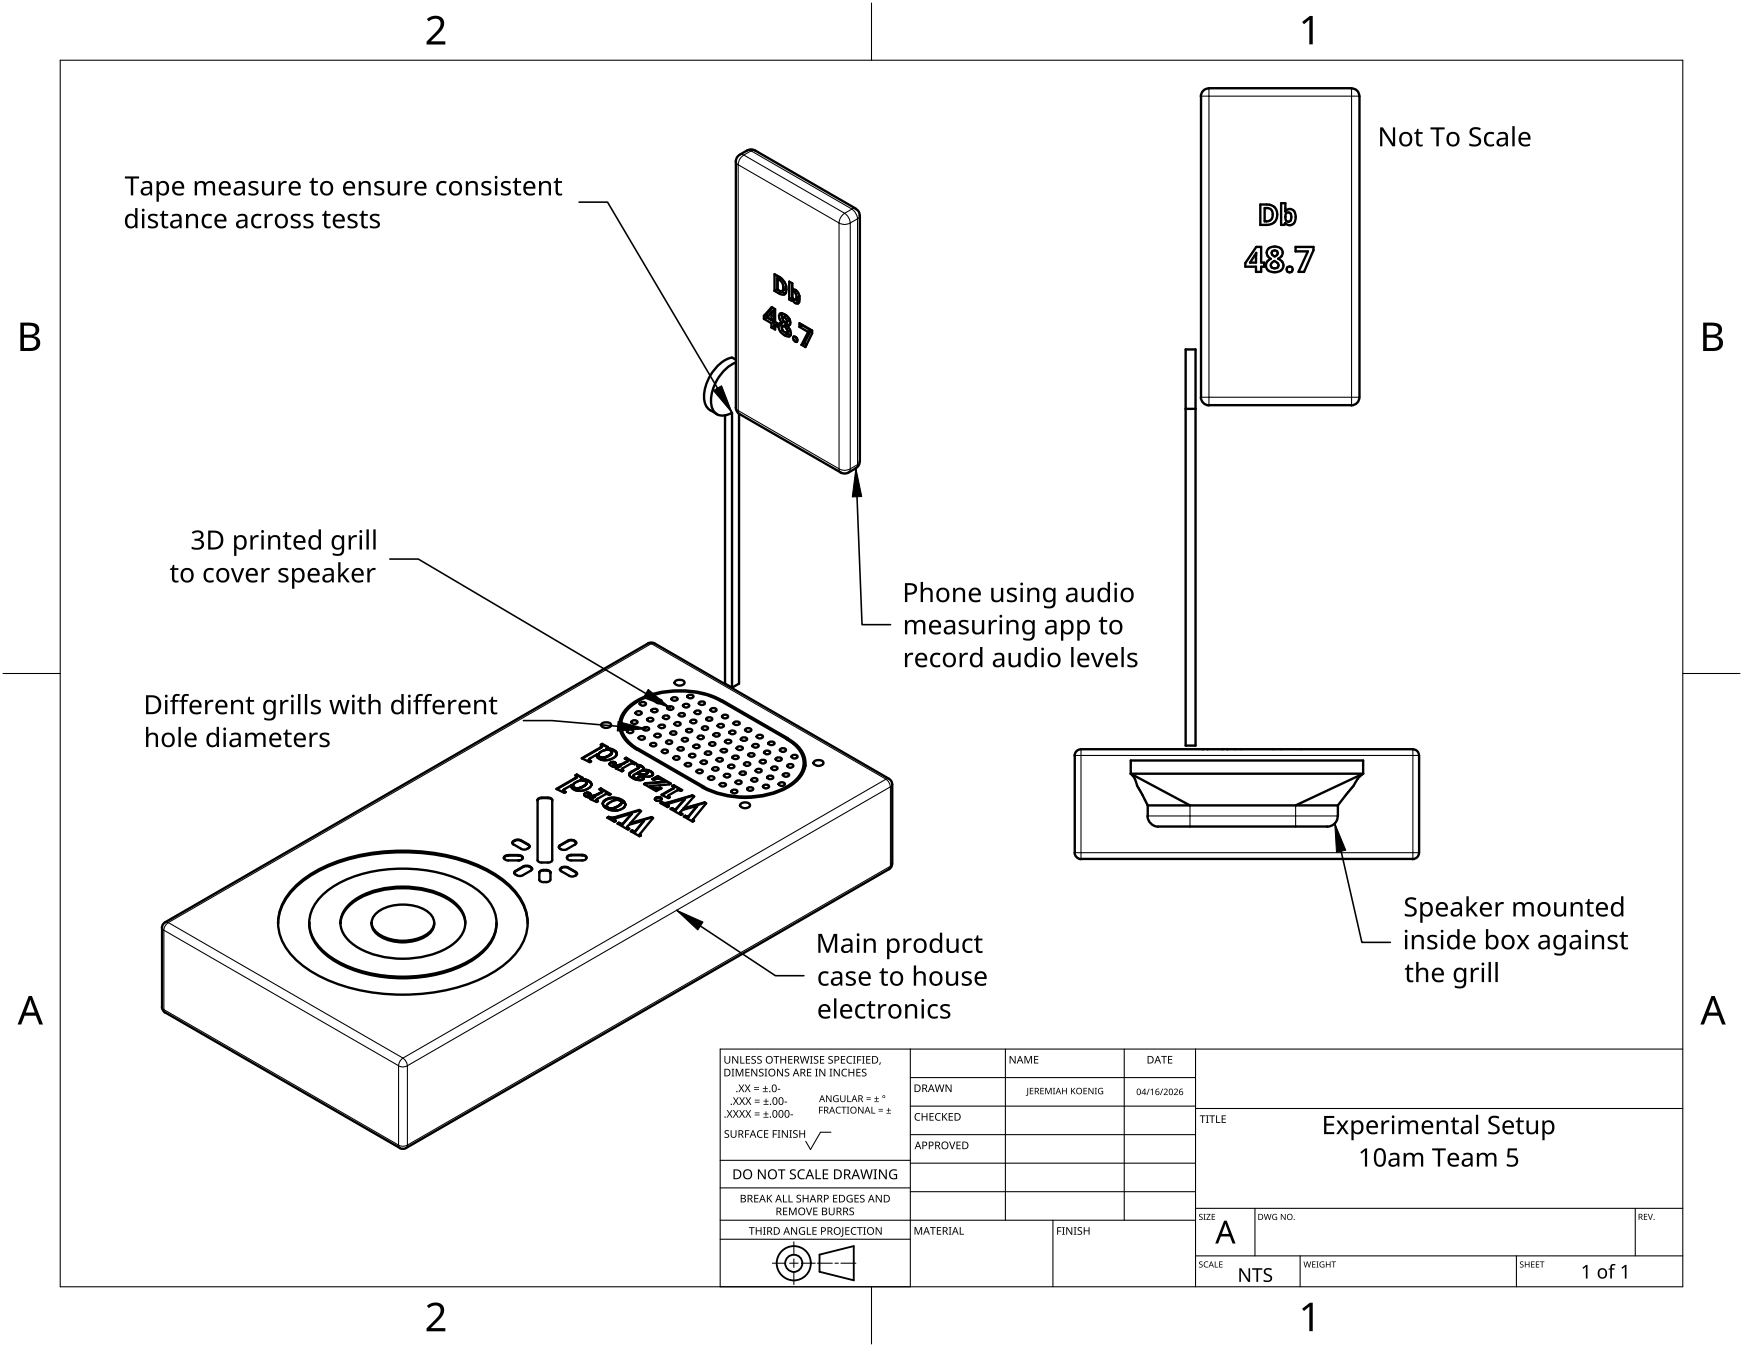
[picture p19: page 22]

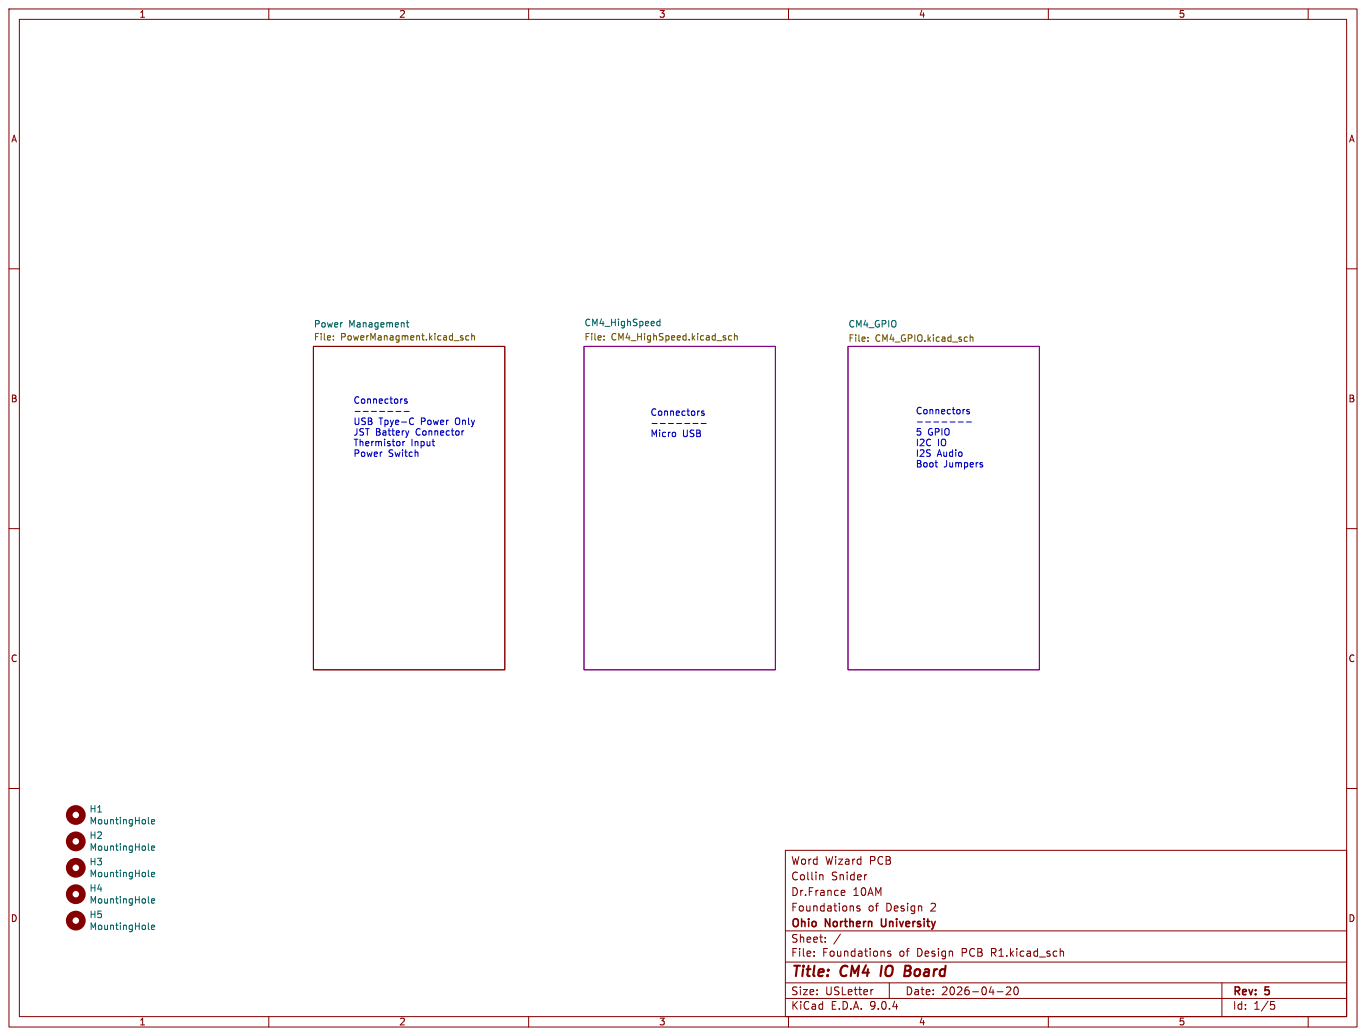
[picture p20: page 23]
D Date: 2026-04-20 KiCad; E.D.A. 9.0.4 Size: USLetter; Rev: 5; File: Foundations; Design; PCB; R1.kicad_sch Sheet: / Ohio; Northern University Foundations; Design 2 Dr.France 10AM; Collin Snider Word; Wizard; CM4_GPIO; File: CM4_GPIO.kicad_sch CM4_HighSpeed File: CM4_HighSpeed.kicad_sch Power Management File: PowerManagment.kicad_sch H5 MountingHole H4 MountingHole H3 MountingHole H2 MountingHole H1 MountingHole; Connectors; ------- 5 GPIO; JST Battery Connector Thermistor; Input Power Switch

------- Micro USB Connectors
------- USB Tpye-C Power Only

I2S Audio Boot Jumpers Connectors

Id: 1/5 Title: CM4 IO Board

1 | 2 | 3 | 4 | 5

A

BC

D

A

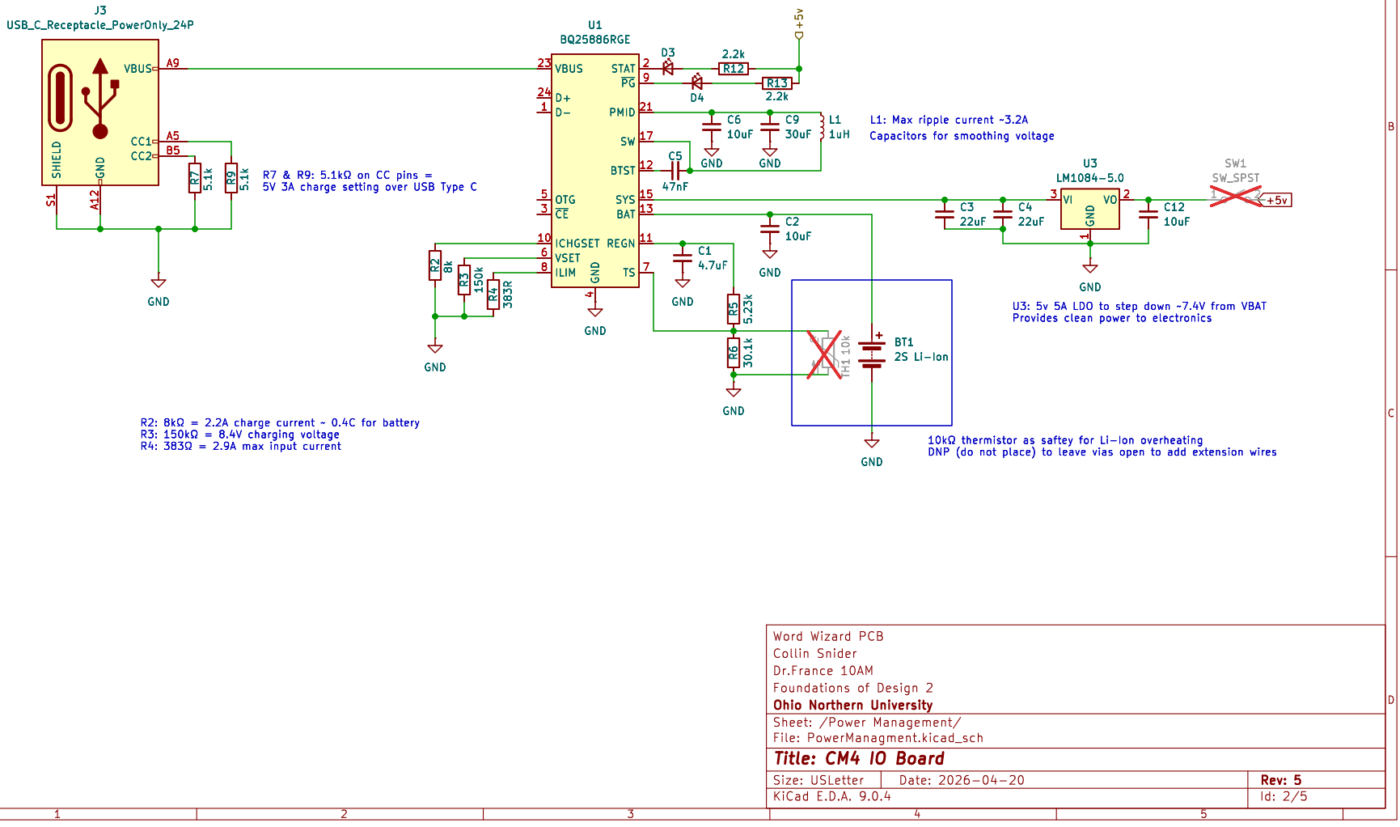
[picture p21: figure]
D Date: 2026-04-20 KiCad; E.D.A. 9.0.4 Size: USLetter; Rev: 5; Id: 2/5 Title: CM4 IO Board; File: PowerManagment.kicad_sch Sheet: /Power; Management/ Ohio; Northern University Foundations; Design 2 Dr.France 10AM; Collin Snider Word; Wizard; PCB SHIELD S¹; GND A¹²; VBUS; J3 USB_C_Receptacle_PowerOnly_24P; BT1 2S Li-Ion TH¹ ¹⁰k GND; 22uF TH¹ ¹⁰k; GND; 2.2k C5 47nF VBUS 23 D+ 24 D- 1 OTG 5 ~{CE} 3; ICHGSET 10 VSET 6; ILIM 8; VBUS 23 D+ 24 D- 1 OTG 5 ~{CE} 3; GND GND; 2 SW1 SW_SPST C2; 2 SW1 SW_SPST D3; 10uF GND R⁵ 5.23k GND R⁹ 5.1k; 10uF R⁴ 383RR³ 150kR² 8k; 22uF R13 2.2k GND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

4 STAT 2 ~{PG}9 PMID 21 SW 17 BTST 12 SYS 15 BAT 13 REGN 11 TS 7 U1 BQ25886RGE GND

4 STAT 2 ~{PG}9 PMID 21 SW 17 BTST 12 SYS 15 BAT 13 REGN 11 TS 7 U1 BQ25886RGE GND GND R7 5.1k GND R4 383R SHIELD S1 GND A12 VBUS A9 CC1 A5 CC2 B5

30uF⁺⁵v | +5v þÿ10k©thermistor | as saftey for Li-Ion | overheating DNP (do not place) to leave vias open to add extension | wires U3: 5v 5A LDO to step down ~7.4V from VBAT Provides clean power to electronics þÿ10k©thermistor | as saftey for Li-Ion | overheating DNP (do not place) to leave vias open to add extension | wires U3: 5v 5A LDO to step down ~7.4V from VBAT Provides clean power to electronics D4 PG "Power Good" LED
Active when external | power supply is plugged in D4 PG "Power Good" LED
Active when external | power supply is plugged in Capacitors | for smoothing | voltage
L1: Max ripple current ~3.2A Capacitors | for smoothing | voltage D3 Stat "status" | LED
Solid = charging Off = charged Blink = fault R7 & R9: þÿ5.1k©on CC pins =
L1: Max ripple current ~3.2A D3 Stat "status" | LED
Solid = charging Off = charged Blink = fault R2: þÿ8k©= 2.2A charge current ~ 0.4C for battery R3: þÿ150k©= 8.4V charging | voltage R4: þÿ383©= 2.9A max input current R2: þÿ8k©= 2.2A charge current ~ 0.4C for battery R3: þÿ150k©= 8.4V charging | voltage R4: þÿ383©= 2.9A max input current GND | R⁷ 5.1k
10uF R⁵ 5.23k GND GND R⁹ 5.1k | R⁴ 383RR³ 150kR² 8k | R⁶ 30.1k | C4

# 4 STAT 2 ~{PG}9 PMID 21 SW 17 BTST 12 SYS 15 BAT 13 REGN 11 TS 7 U1 BQ25886RGE

# 4 STAT 2 ~{PG}9 PMID 21 SW 17 BTST 12 SYS 15 BAT 13 REGN 11 TS 7 GND GND

USB_OTG_ID 101 USB2_N 103 USB2_P 105 GND 107 PCIe_nRST 109 VDAC_COMP 111 GND 113 CAM1_D0_N 115 CAM1_D0_P 117 GND 119 CAM1_D1_N 121 CAM1_D1_P 123 GND 125 CAM1_C_N 127 CAM1_C_P 129 GND 131 CAM1_D2_N 133 CAM1_D2_P 135 GND 137 CAM1_D3_N 139 CAM1_D3_P 141 HDMI1_HOTPLUG 143 HDMI1_SDA 145 HDMI1_SCL 147 HDMI1_CEC 149 HDMI0_CEC 151 HDMI0_HOTPLUG 153 GND 155 DSI0_D0_N 157 DSI0_D0_P 159 GND 161 DSI0_D1_N 163 DSI0_D1_P 165 GND 167 DSI0_C_N 169 DSI0_C_P 171 GND 173 DSI1_D0_N 175 DSI1_D0_P 177 GND 179 DSI1_D1_N 181 DSI1_D1_P 183 GND 185 DSI1_C_N 187 DSI1_C_P 189 GND 191 DSI1_D2_N 193 DSI1_D2_P 195 GND 197 HDMI0_SDA 199

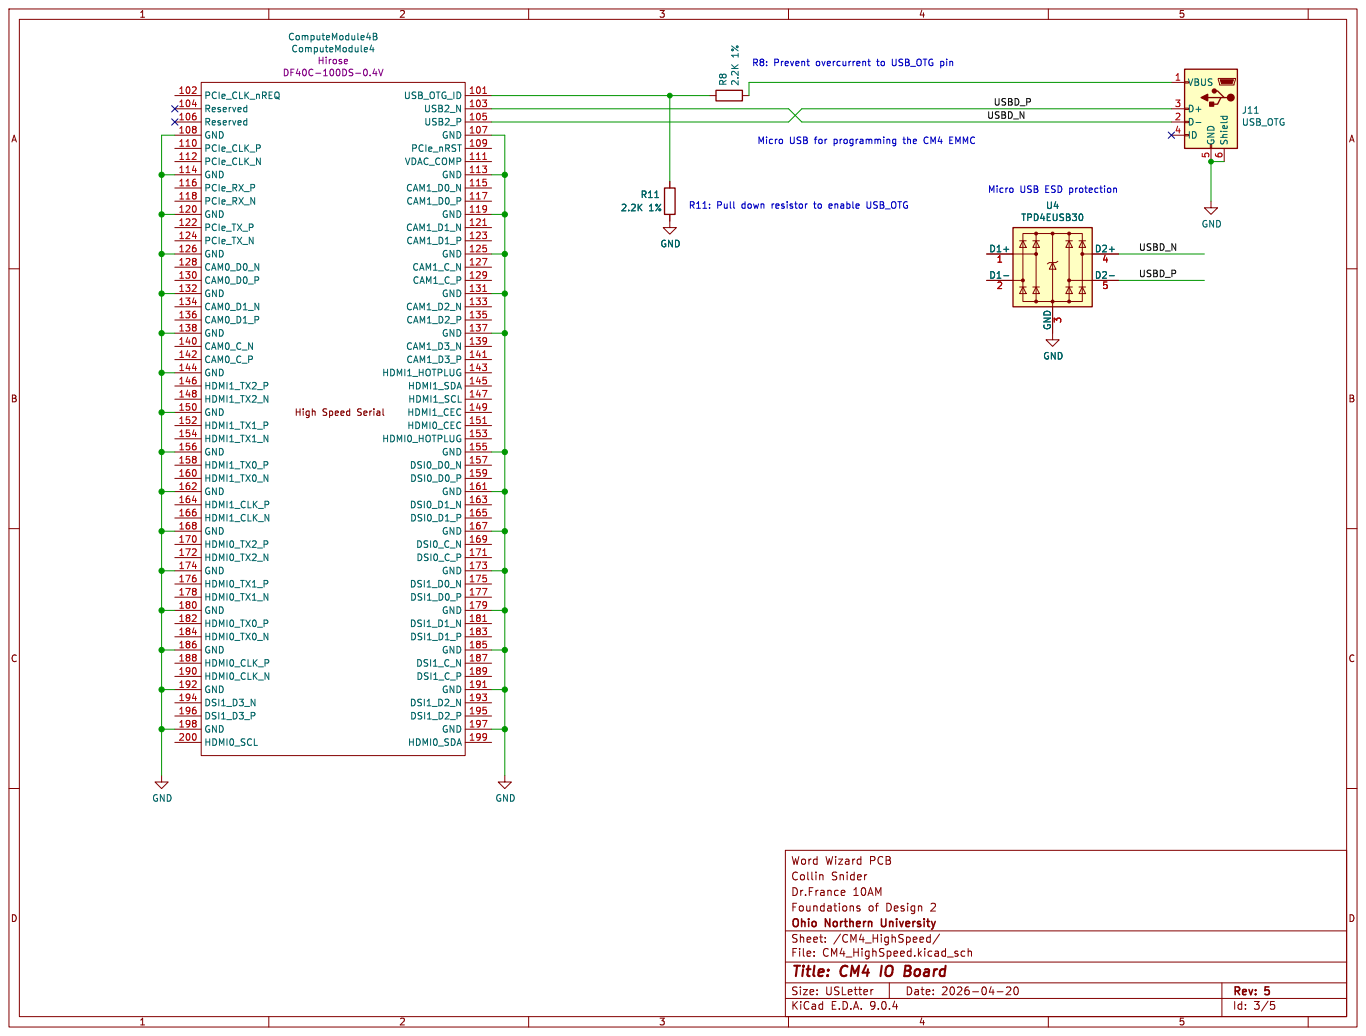
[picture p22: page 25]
5 ABCD; ABCD Date: 2026-04-20 KiCad; E.D.A. 9.0.4 Size: USLetter; Rev: 5; File: CM4_HighSpeed.kicad_sch Sheet: /CM4_HighSpeed/ Ohio; Northern University Foundations; Design 2 Dr.France 10AM; Collin Snider Word; Wizard; PCB; GND; Shield 6 GND 5 VBUS 1 D+ 3 D- 2; J11 USB_OTG; GND R⁸ 2.2K ¹%; GND3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

Id: 3/5 Title: CM4 IO Board

# 1k GND

# Activity LED J1 DNP for vias

ID_SD 36 GPIO11 38 GPIO9 40 GND 42 GPIO10 44 GPIO22 46 GPIO27 48 GPIO17 50 GND 52 GPIO4 54 GPIO3 56 GPIO2 58 GND 60 SD_CMD 62 SD_DAT5 64 GND 66 SD_DAT4 68 SD_DAT7 70 SD_DAT6 72 GND 74 Reserved 76 GPIO_VREF(1.8v/3.3v_Input) 78 SCL0 80 SDA0 82 +3.3v_(Output) 84 +3.3v_(Output) 86 +1.8v_(Output) 88 +1.8v_(Output) 90 RUN_PG 92 AnalogIP1 94 AnalogIP0 96 GND 98

GND 2 Ethernet_Pair1_P 4 Ethernet_Pair1_N 6 GND 8 Ethernet_Pair0_N 10 Ethernet_Pair0_P 12 GND 14 Ethernet_SYNC_IN(1.8v) 16 Ethernet_SYNC_OUT(1.8v) 18 EEPROM_nWP 20 GND 22 GPIO26 24 GPIO19 26 GPIO13 28 GPIO6 30 GND 32 GPIO5 34

on modules without eMMC GPIO

600mA Max 600mA Max NB SD signals are only available

I2C in for NFC reader EEPROM write protect = Jumper Pins 3-4

Id: 4/5 Title: CM4 IO Board

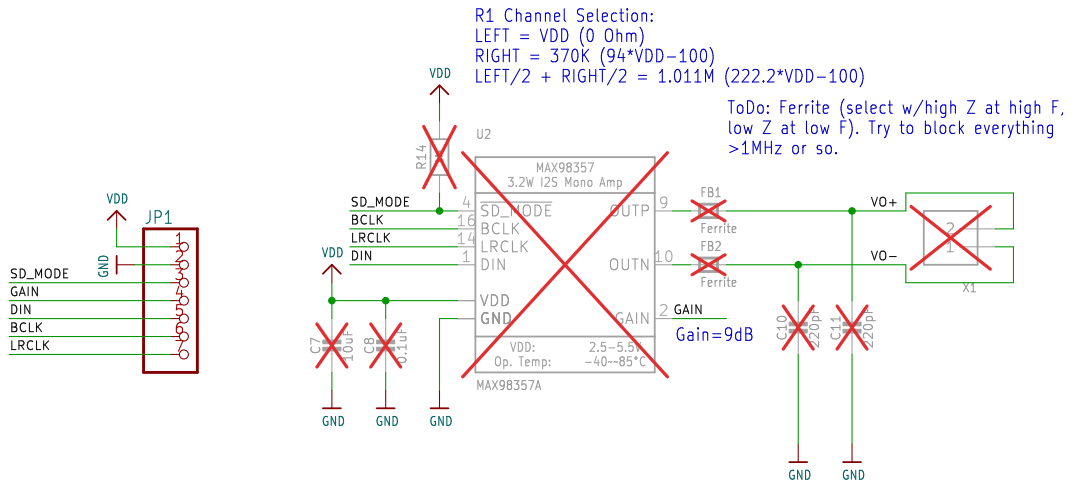
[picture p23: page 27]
D Date: 2026-04-20 KiCad; E.D.A. 9.0.4 Size: USLetter; Rev: 5; File: Adafruit; PCM5122; DAC.kicad_sch Sheet: /CM4_GPIO/DAC/ Ohio; Northern University Foundations; Design 2 Dr.France 10AM; Collin Snider Word; Wizard; PCB R¹⁴; 1M VDD; VDD; VDD:; Op. Temp: MAX98357; I2S Mono Amp; ~{SD_MODE} 4; BCLK 16; LRCLK 14; DIN 1; VDD GND; OUTP; 9 OUTN 10 GAIN; 2 U2 MAX98357A; FB1 Ferrite FB2 Ferrite; C¹⁰; 220pF C¹¹; 220pF GND; GND GND VDD; GND; 0.1uF GND; GND C⁷; 10uF DIN; VO- VO+ DIN; GAIN; LRCLK; BCLK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

LEFT = VDD (0 Ohm)
RIGHT = 370K (94*VDD-100)

Id: 5/5 Title: CM4 IO Board

# Appendix 4: Budget Tracker

# Appendix 5: Gantt Chart

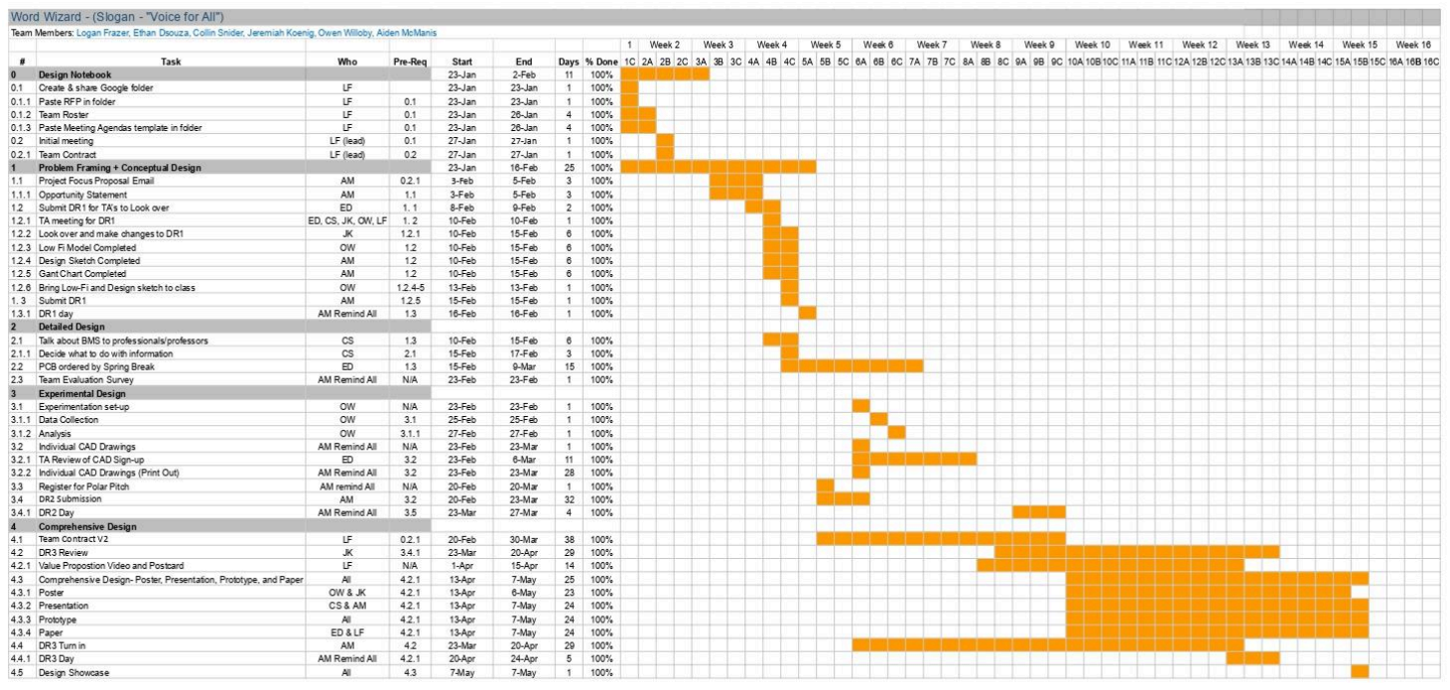
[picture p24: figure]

# Appendix 6: AI Disclosure

AI was used in problem framing, refining text, and programming the device. AI models used

were Claude, Gemini, ChatGPT, and GPAI.

# Appendix 7: Electronics Troubleshooting

Troubleshooting:

Unfortunately, but expectedly one of the most time consuming aspects of the project was attempting to diagnose an intermittent problem on the custom PCB. The code and hardware had previously been proven for functionality on a development board with jumpers, however upon transferring the compute module and components it began to encounter an error. For unknown reasons at the time, the board would function as expected on the surface level for about 20-30 seconds after boot up. However, when a card was introduced after this period it would lead to a boot cycle. The first diagnosing step taken was to isolate any potential power problems. Each board was given its own power supply and retested. Yet, the issue was not so simple. Next, the PN532 was hooked up to an oscilloscope to analyze its I2C data bus. See below.


Figure 12: I2C communication, CH1 5V power, CH2 SDA

There are many details to note in this snapshot. First, we can note that the noise in the 5V rail is acceptable as it is well within the tolerance of ±5% or ±0.25V. Next, The I2C data line is not achieving full logic high of 3.3V. In the testing, it showed a maximum value of 3.1V. This is most concerning. It should be noted that there had been 2kΩ pull-up resistors to each I2C pin to achieve functionality. Since these pull-ups were in place, the logic high should always be 3.3V. In further reviewing of datasheets, these pull-ups were not necessary, as the board has internal 1.8kΩ pull-up resistors. However, the fact that the logic rail was not returning to 3.3V still suggested that something was ‘fighting’ the external pull up resistors. Our next hint comes from the failure mode of the I2C data pin. After about 20-30 seconds of abnormal operation, the data rail would return to 2.31V, once again despite the 3.3V pull-up resistors. This clearly shows that the board had detected some sort of fault and entered a fail-safe mode, powering down itself.

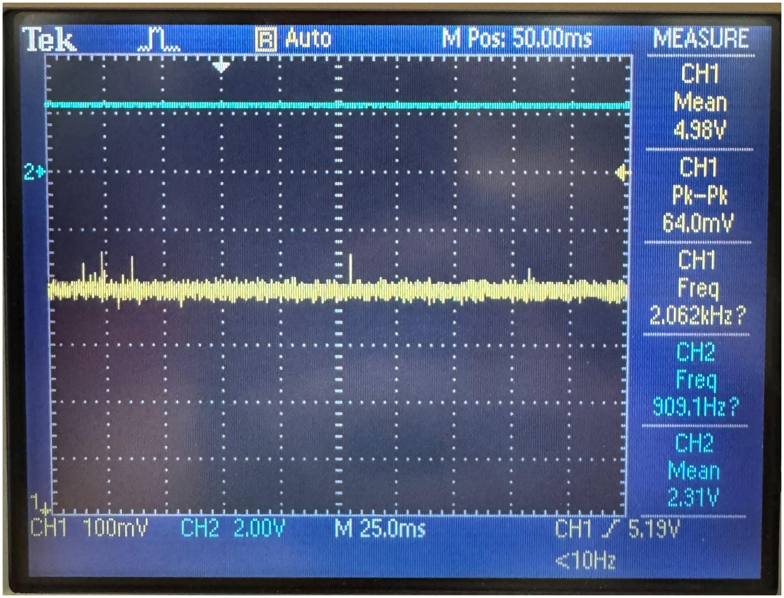
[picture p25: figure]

Figure 13: CM4 power shutoff, CH1 5V power, CH2 SDA

These specific fail cases led us to believe that something on the board was left ‘floating’ or not connected, as these issues did not occur with the exact same setup as the development board. After a complete review of development board schematics to ensure no circuitry was absent on the custom board, we went to review forums suggesting which pins left floating may cause such an issue. After much research, there were a few options to test, including enable or reset pins, however, GPIO_VREF turned out to be the pin that matched our exact symptoms. This input is the voltage reference which must be pulled directly to 1.8V or 3.3V to determine the logic level of the GPIO pins. Since it was left floating, it averaged to the mean between 0 and 5V, or approximately 2.3V. A simple overlook, and catastrophic consequences. This explains each problem we encountered, the external pull-ups, although enough to make the threshold of logic high, caused an extra thermal load in the GPIO controller, since 3.3V were ‘fighting’ the 2.5V reference. This explains how the board knew something was awry and reset itself by thermal protections, which realised about 20-30 seconds afterboot. The solution to this problem was to manually adjust the PCB traces and hardwire the voltage reference to 3.3V as it should have been designed.

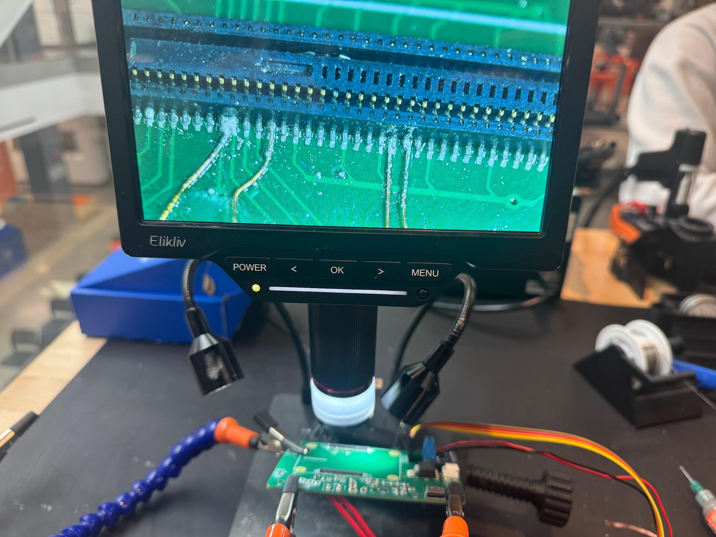
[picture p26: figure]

Figure 13: Manually adjusting PCB traces to Hirose connector

The above Figure 13, demonstrates the scale at which this repair had to be made, another previous adjustment can be seen. This was an attempt to rule out software errors, the I2C pins were swapped to ones that would match the development board to try to control as many variables as possible. On the next page, Figure 14, is a close up of the soldering process. Note that the wires pictured are 39 AWG or approximately 3 thousandths of an inch in diameter. A pair of 3.3V pins are leftmost, and the GPIO_ VREF is the adjacent solder connection. This process took a few hours alone to perfect. Too little or too much solder could lead to further complications.

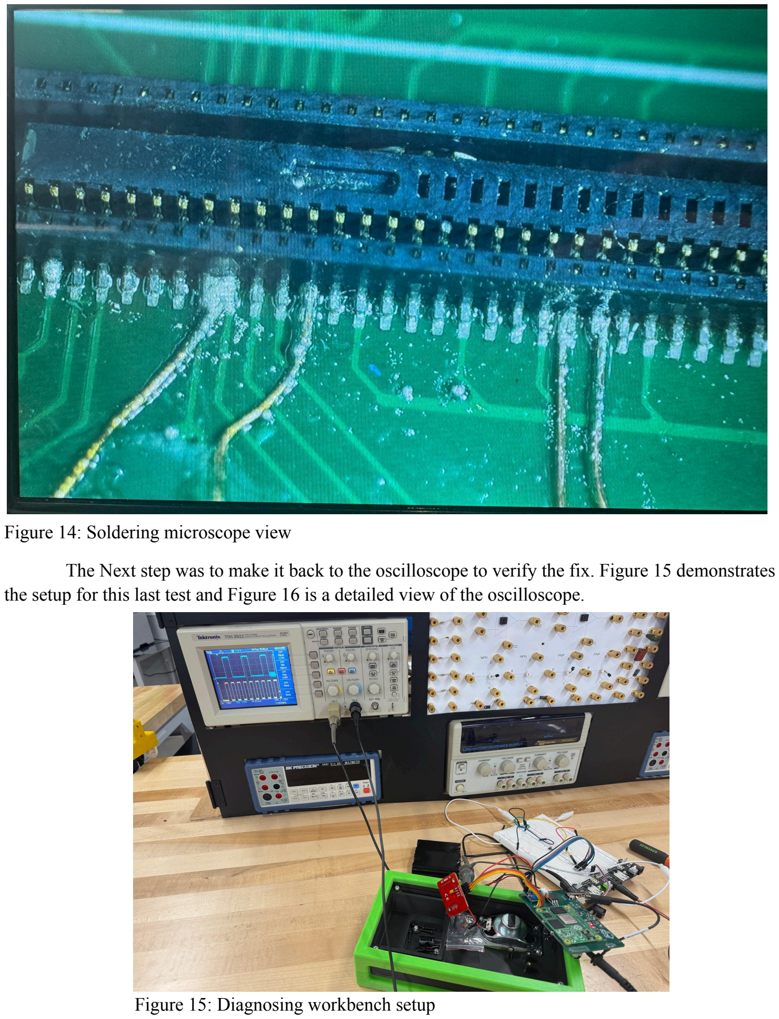
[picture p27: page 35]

Figure 14: Soldering microscope view

The Next step was to make it back to the oscilloscope to verify the fix. Figure 15 demonstrates the setup for this last test and Figure 16 is a detailed view of the oscilloscope.

Figure 15: Diagnosing workbench setup

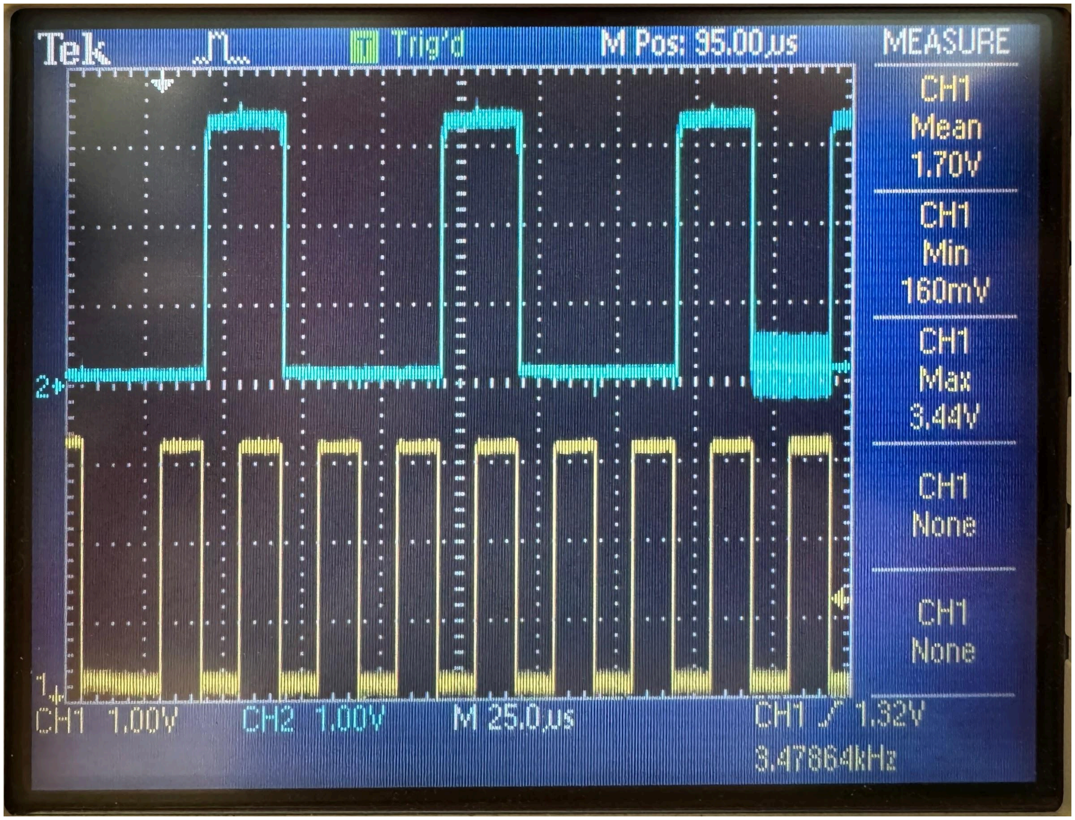
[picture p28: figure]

Figure 16: Fixed GPIO_VREF and digital communications. CH1 I2C SCL, CH2 I2C SDA

The results were exactly what we had hoped to see, clean rising and falling edges, well beyond the logic voltage thresholds. This overlook turned into a much harder to chase problem, however the lessons learned in the troubleshooting and diagnosing process are much greater than they would have been if everything had gone to plan. This problem turned out to be an invaluable teaching moment in both the art of measurement tools, soldering, but also emphasized the importance of checking, double checking, and peer reviewing designs whenever possible.

# Appendix 8: User Manual

Word Wizard — Educator Reference Manual

# Word Wizard

## Educator Reference Manual

Setup • Daily Operation • Care • Safety
Ohio Northern University – Team 5 | 2026

Ohio Northern University — Team 5

Word Wizard — Educator Reference Manual

## Introduction

Word Wizard is a portable, NFC-based augmentative and alternative communication (AAC) device designed to support non-verbal individuals in educational settings. When a communication card is tapped on the device, Word Wizard speaks the corresponding word or phrase aloud using a built-in text-to-speech (TTS) engine.

This manual covers everything a teacher or classroom staff member needs to set up, operate, maintain, and safely care for the device.

## Safety Warnings

⚠️ SCREWS / FASTENERS
The enclosure uses accessible screws to allow component servicing. Do not allow unsupervised individuals to open the device. Loose screws are a choking and injury hazard.

⚠️ BATTERY SAFETY
Do not expose the device to extreme heat, puncture the enclosure, or submerge in liquid. Use any USB-C cable and a standard 5V charger. If the device becomes hot to the touch, smells unusual, or shows signs of swelling, discontinue use immediately.

⚠️ DROP RISK
Although the TPU bumper provides impact resistance for drops up to approximately 3 feet onto hard flooring, repeated or severe impacts can still damage internal components. Inspect the device after any significant drop.

## What’s in the Box

- Word Wizard device (with TPU bumper attached)
- Communication card set (color-coded per grammatical group)
- Card storage drawer

📌 NOTE
Additional communication cards can be programmed using a smartphone with NFC write capability. See Section 5 for details.

Ohio Northern University — Team 5

Word Wizard — Educator Reference Manual

## Setup & First Use

Charging the Device
1. Connect the USB-C cable to the port on the back of the device.
2. Plug the other end into a standard USB wall adapter (5V recommended).
3. If powered on, green and orange status indicator lights will confirm charging is in progress. If the lights are blinking, disconnect charger and discontinue use.
4. Allow a full charge before first use. The battery capacity is at least 40 Watt-hours, providing extended daily use on a single charge.

📌 TIP
Charge overnight before the first school day. We recommend charging each evening to ensure a full battery every morning.

Powering On
1. Toggle the power switch on the side.
2. The device will boot and be ready to use in less than a minute.
3. Place the device on a flat, stable surface accessible to the student.

## Daily Operation

Using Communication Cards
Each communication card contains an embedded NFC tag. When a card is tapped on the top surface of the device, Word Wizard will speak the corresponding word or phrase aloud.
1. Hold the card flat and touch it to the NFC reader area, indicated by the magic wand logo.
2. The device will respond within a moment and speak the word.
3. Return the card to the storage drawer when not in use.

Ohio Northern University — Team 5

Word Wizard — Educator Reference Manual

Card Color Coding (based on the Fitzgerald Key)
Cards follow the Fitzgerald Key color coding system, a widely recognized AAC standard that reduces cognitive load by grouping words by grammatical category:
Color | Category | Examples
Yellow | Question Words | why, where, how
Orange | Action Words | hungry, help, stop
Green | Social Words | yes, no, thank you
Pink | People | Mom, brother, grandma

Volume
The device is calibrated to output 60–65 dB at ear level, consistent with normal speech.

Language Support
Word Wizard uses the Piper TTS engine, which supports multiple languages and dialects. Contact the ONU Engineering Department if language or dialect settings need to be changed for a specific student.

## Programming & Customizing Cards

One of the key advantages of Word Wizard is that communication cards can be customized or reprogrammed without purchasing new hardware. You will need a smartphone with NFC write capability (most modern Android and iOS devices support this).

1. Download a free NFC writing app on your smartphone (e.g., “NFC Tools” for iOS or Android).
2. Open the app and select “Write”, then “Add a Record”, then “Text”.
3. Enter the word or phrase you want the card to speak.
4. Select “Write / X Bytes” and hold the blank or existing NFC card against the back of your phone until the app confirms a successful write.
5. Tap the newly programmed card on Word Wizard to verify it works correctly.

📌 NOTE
NFC programming requires a smartphone capable of NFC write functionality. The device must be powered on to play a card, but does not need to be connected to a network. Cards can be reprogrammed as many times as needed.

Ohio Northern University — Team 5

Word Wizard — Educator Reference Manual

## Charging & Battery Care

- Use only standard USB-C cables rated for 5V charging.
- Avoid charging in direct sunlight or in environments above 35°C (95°F).
- Do not leave the device fully discharged for extended periods.
- A rechargeable internal battery means no disposable batteries are needed, reducing waste.
- If the device will not be used for more than one week, store it with a partial charge (around 50%).

⚠️ DO NOT
Do not use non-standard or high-wattage fast chargers not rated for the device. Do not attempt to replace the battery yourself; contact the ONU Engineering Dept.

## Cleaning & Hygiene

Word Wizard is designed with school hygiene in mind. The PLA enclosure and TPU bumper can be wiped down regularly without degradation.

Recommended Cleaning Method
1. Power off the device before cleaning.
2. Use a cloth lightly dampened with water and/or a gentle cleaning solution.
3. Avoid using alcohol to clean the acrylic back plate to reduce the risk of solvent stress cracking.
4. Wipe all exterior surfaces, including the bumper and NFC reader area.
5. Allow to dry fully before powering back on.
6. The communication cards can be wiped with the same method.

⚠️ AVOID
Do not submerge the device in any liquid. Do not spray cleaners directly onto the device. Do not use abrasive materials or bleach-based cleaners, which may damage surface materials.

📌 NOTE
Surface pores in 3D-printed parts may accumulate debris over time. Consistent wiping with cleaning solutions helps minimize bacterial buildup.

Ohio Northern University — Team 5

Word Wizard — Educator Reference Manual

## Communication Card Storage

The device includes an integrated card storage drawer at the base, organized by a modified Fitzgerald Key color coding. 40+ cards can be stored in the drawer.

- Keep cards sorted by color category for easy retrieval.
- Return cards to the drawer after each use to minimize loss.
- Cards should be stored flat to prevent bending or damage to the NFC chip.
- Consider labeling the drawer sections by color group if students manage cards independently.

📌 TIP
Use the pictogram or image printed on the card face to help students identify and select cards independently, reducing reliance on reading ability.

## Troubleshooting

Problem | Likely Cause | Solution
Device does not power on | Battery depleted | Charge device for at least 30 minutes before retrying.
Card tap produces no sound | Card not aligned / NFC issue | Re-tap the card flat and centered on the reader area. Try a different card to isolate the issue.
Sound is too quiet | Grill obstruction | Ensure speaker grill is clear of debris. Wipe grill with a dry cloth.
Card speaks the wrong word | Card was reprogrammed incorrectly | Re-write the card using the NFC programming steps in Section 5.
Device feels hot during charging | Charging environment too warm | Move device to a cooler location. If heat persists after moving, discontinue charging.
Device does not charge | Cable or port issue | Try a different USB-C cable or charger. Inspect port for debris and clear gently with a dry toothpick if needed.

Ohio Northern University — Team 5

Word Wizard — Educator Reference Manual

📌 STILL HAVING ISSUES?
If the problem is not resolved by the steps above, do not attempt to open the device enclosure. Contact your building administrator or the team responsible for device maintenance.

## Quick Reference Card

Cut out or print this section and post it near the device for easy access.

✅ Daily Startup Checklist
□ Device charged overnight
□ Power on–wait for “Powered On” vocal indicator □ Cards sorted in drawer by color
□ Device placed within student’s reach
□ Test one card tap before class begins

⚠️ Key Reminders
- USB-C only for charging
- Wipe with damp cloth, never submerge
- Do not open the enclosure
- Report issues to ONU Engineering Dept.

Ohio Northern University — Team 5

# Appendix 9: Code

Untitled-1

1 | /**
2 | * Python script to read NFC card and push text data to Piper TTS
3 | * rpi_read_ndef_text.c
4 | *
5 | * Reads NDEF Text records from NFC cards (NTAG2xx / Mifare Ultralight)
6 | * using the pn532-lib on Raspberry Pi.
7 | *
8 | * Based on: https://github.com/soonuse/pn532-lib/blob/master/examples/raspberrypi/rpi_dump_ntag2.c
9 | *
10 | * Build:
11 | * | gcc -o rpi_read_ndef_text rpi_read_ndef_text.c -lpn532 -lpn532_rpi
12 | *
13 | * Wiring (I2C, default):
14 | * | PN532 SDA -> RPi GPIO 2 (Pin 3)
15 | * | PN532 SCL -> RPi GPIO 3 (Pin 5)
16 | * | PN532 VCC -> 3.3V or 5V
17 | * | PN532 GND -> GND
18 | */
19
20 | #include <stdio.h>
21 | #include <stdint.h>
22 | #include <string.h>
23 | #include "pn532.h"
24 | #include "pn532_rpi.h"
25
26 | /* ── NTAG2xx layout ──────────────────────────────────────────────────────────
27 | * Block 0-3 : UID / lock bytes / capability container
28 | * Block 4+ | : user data (TLV-encoded NDEF messages)
29 | * Last blocks: dynamic lock / CFG (tag-size dependent)
30 | *
31 | * Each block is 4 bytes; total user blocks vary by tag variant:
32 | * | NTAG213 → blocks 4-39 | (144 bytes)
33 | * | NTAG215 → blocks 4-129 (496 bytes)
34 | * | NTAG216 → blocks 4-225 (888 bytes)
35 | * We read up to block 135 (same ceiling as the dump example).
36 | * ─────────────────────────────────────────────────────────────────────────── */
5/7/26, 4:05 PM | Untitled-1
localhost:50544/79a13a43-de2d-4c36-b1ab-19da171d6d73/ | 1/8

37
38 | #define MAX_BLOCKS | 135
39 | #define BLOCK_SIZE | 4
40 | #define USER_START_BLOCK 4 | /* first data block */
41
42 | /* TLV tags */
43 | #define TLV_NULL | 0x00
44 | #define TLV_NDEF | 0x03
45 | #define TLV_TERMINATOR 0xFE
46
47 | /* NDEF TNF (Type Name Format) mask */
48 | #define NDEF_TNF_MASK | 0x07
49 | #define NDEF_TNF_WELL_KNOWN 0x01
50
51 | /* NDEF flags */
52 | #define NDEF_FLAG_MB | 0x80 /* Message Begin */
53 | #define NDEF_FLAG_ME | 0x40 /* Message End | */
54 | #define NDEF_FLAG_SR | 0x10 /* Short Record | */
55
56 | /* NDEF Well-Known Type: "T" = Text */
57 | #define NDEF_TYPE_TEXT 'T'
58
59 | /* ── Helper: print raw hex bytes ─────────────────────────────────────────── */
60 | static void print_hex(const uint8_t *data, size_t len)
61 | {
62 | for (size_t i = 0; i < len; i++) {
63 | printf("%02X ", data[i]);
64 | }
65 | printf("\n");
66 | }
67
68 | /* ── Parse and print one NDEF Text record payload ────────────────────────── */
69 | /*
70 | * Text record payload format (RFC 5646):
71 | * | Byte 0 | : status byte – bit7=UTF16, bits5-0=lang length
72 | * | Bytes 1..L | : language code (e.g. "en")
73 | * | Bytes L+1..N : text (UTF-8 or UTF-16)
74 | */
5/7/26, 4:05 PM | Untitled-1
localhost:50544/79a13a43-de2d-4c36-b1ab-19da171d6d73/ | 2/8

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
) !=

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
6, 4:0

5

P

M

U

n

title

d

1 localhost:50544/79a13a43-de2d-4c36-b1ab-19da171d6d73/

3

/

8

113 | }
114 | putchar('\n');
115 | }
116
117 | /* ── Walk the TLV stream in the user-data buffer ────────────────────────── */
118 | static void parse_ndef_tlv(const uint8_t *data, size_t data_len)
119 | {
120 | size_t pos | = 0;
121 | int | found_any = 0;
122
123 | while (pos < data_len) {
124 | uint8_t tag = data[pos++];
125
126 | if (tag == TLV_NULL) | { continue; }
127 | if (tag == TLV_TERMINATOR) { break; | }
128
129 | if (pos >= data_len) break;
130
131 | /* TLV length – extended (3-byte) form if 0xFF */
132 | uint32_t length;
133 | if (data[pos] == 0xFF) {
134 | if (pos + 2 >= data_len) break;
135 | length = ((uint32_t)data[pos + 1] << 8) | data[pos + 2];
136 | pos += 3;
137 | } else {
138 | length = data[pos++];
139 | }
140
141 | if (pos + length > data_len) {
142 | printf("[!] TLV value exceeds buffer – tag 0x%02X, len %u\n",
143 | tag, length);
144 | break;
145 | }
146
147 | if (tag != TLV_NDEF) {
148 | pos += length; /* skip unknown TLV */
149 | continue;
150 | }
5/7/26, 4:05 PM | Untitled-1
localhost:50544/79a13a43-de2d-4c36-b1ab-19da171d6d73/ | 4/8

151
152 | /* ── Found an NDEF message TLV ─────────────────────────── */
153 | const uint8_t *ndef_msg | = data + pos;
154 | size_t | ndef_remain = length;
155 | pos += length;
156
157 | /* Walk individual NDEF records inside the message */
158 | size_t rpos = 0;
159 | while (rpos < ndef_remain) {
160 | if (rpos + 3 > ndef_remain) break;
161
162 | uint8_t flags | = ndef_msg[rpos++];
163 | uint8_t type_len = ndef_msg[rpos++];
164
165 | /* Payload length: SR flag → 1 byte, else 4 bytes */
166 | uint32_t payload_len;
167 | if (flags & NDEF_FLAG_SR) {
168 | if (rpos >= ndef_remain) break;
169 | payload_len = ndef_msg[rpos++];
170 | } else {
171 | if (rpos + 4 > ndef_remain) break;
172 | payload_len = ((uint32_t)ndef_msg[rpos | ] << 24) |
173 | ((uint32_t)ndef_msg[rpos + 1] << 16) |
174 | ((uint32_t)ndef_msg[rpos + 2] << 8) |
175 | (uint32_t)ndef_msg[rpos + 3];
176 | rpos += 4;
177 | }
178
179 | /* ID length (if IL flag set) */
180 | uint8_t id_len = 0;
181 | if (flags & 0x08) { /* IL flag */
182 | if (rpos >= ndef_remain) break;
183 | id_len = ndef_msg[rpos++];
184 | }
185
186 | if (rpos + type_len + id_len + payload_len > ndef_remain) break;
187
188 | const uint8_t *type | = ndef_msg + rpos; rpos += type_len;
5/7/26, 4:05 PM | Untitled-1
localhost:50544/79a13a43-de2d-4c36-b1ab-19da171d6d73/ | 5/8

189 | /* skip ID */ | rpos += id_len;
190 | const uint8_t *payload = ndef_msg + rpos; rpos += payload_len;
191
192 | uint8_t tnf = flags & NDEF_TNF_MASK;
193
194 | printf("\n[NDEF Record]\n");
195 | printf(" TNF | : 0x%02X (%s)\n", tnf,
196 | tnf == NDEF_TNF_WELL_KNOWN ? "Well-Known" : "other");
197
198 | if (type_len > 0) {
199 | printf(" Type | : %c\n", type[0]);
200 | }
201
202 | if (tnf == NDEF_TNF_WELL_KNOWN &&
203 | type_len == 1 && type[0] == NDEF_TYPE_TEXT) {
204 | parse_ndef_text(payload, payload_len);
205 | found_any = 1;
206 | } else {
207 | printf(" Payload : ");
208 | print_hex(payload, payload_len);
209 | }
210
211 | if (flags & NDEF_FLAG_ME) break; /* last record in message */
212 | }
213 | }
214
215 | if (!found_any) {
216 | printf("[i] No NDEF Text records found on this card.\n");
217 | }
218 | }
219
220 | /* ── main ────────────────────────────────────────────────────────────────── */
221 | int main(void)
222 | {
223 | uint8_t block_buf[BLOCK_SIZE];
224 | uint8_t uid[MIFARE_UID_MAX_LENGTH];
225 | uint8_t user_data[MAX_BLOCKS * BLOCK_SIZE];
226 | uint32_t user_data_len = 0;
5/7/26, 4:05 PM | Untitled-1
localhost:50544/79a13a43-de2d-4c36-b1ab-19da171d6d73/ | 6/8

printf("=== PN532 NDEF Text Reader ===\n\n");

PN532 pn532;
/* Choose ONE init method to match your hardware wiring: */ PN532_I2C_Init(&pn532);
/* PN532_SPI_Init(&pn532); */
/* PN532_UART_Init(&pn532); */

uint8_t fw[4];
if (PN532_GetFirmwareVersion(&pn532, fw) != PN532_STATUS_OK) { fprintf(stderr, "[!] PN532 not found. Check wiring.\n"); return -1;
}
printf("[+] PN532 detected – firmware v%d.%d\n\n", fw[1], fw[2]);

PN532_SamConfiguration(&pn532);

printf("Waiting for NFC card...\n");

/* ── Poll until a card is presented ──────────────────────────────── */ int32_t uid_len;
while (1) {
uid_len = PN532_ReadPassiveTarget(&pn532, uid, PN532_MIFARE_ISO14443A, 1000); if (uid_len != PN532_STATUS_ERROR) break; printf(".");
fflush(stdout);
}

printf("\n[+] Card detected!\n");
258 | printf(" | UID: ");
for (int32_t i = 0; i < uid_len; i++) { printf("%02X ", uid[i]);
| }
printf("(%d bytes)\n\n", uid_len);

/* ── Read user data blocks ───────────────────────────────────────── */

5/7/26, 4:05 PM | Untitled-1
localhost:50544/79a13a43-de2d-4c36-b1ab-19da171d6d73/ | 7/8

printf("Reading data blocks...\n");
for (uint8_t blk = USER_START_BLOCK; blk < MAX_BLOCKS; blk++) { uint32_t err = PN532_Ntag2xxReadBlock(&pn532, block_buf, blk); if (err != PN532_ERROR_NONE) {
/* End of readable area (e.g. hit config pages) */
break;
}
memcpy(user_data + user_data_len, block_buf, BLOCK_SIZE); user_data_len += BLOCK_SIZE;
}

printf("[+] Read %u bytes of user data.\n\n", user_data_len);

/* ── Parse TLV / NDEF ────────────────────────────────────────────── */ printf("Parsing NDEF records...\n");
parse_ndef_tlv(user_data, user_data_len);

printf("\nDone.\n");
return 0;
}
5/7/26, 4:05 PM | Untitled-1
localhost:50544/79a13a43-de2d-4c36-b1ab-19da171d6d73/ | 8/8

# References

DR1

[1] “Classroom layout desk & table sizes.” Dimensions.com. https://www.dimensions.com/element/classroom-layout-desk-table-sizes (https://www.dimensions.com/element/classroom-layout-desk-table-sizes?utm_source=chatgpt.com) (accessed Feb. 12, 2026).
[2] BASF Corporation, Elastollan® – Properties: Chemical Properties. https://www.basf.com/dam/jcr:e42483e4-4087-3544-a6a2-f958427c1030/Elastollan_Properties-Chemical-Properties.pdf (https://www.basf.com/dam/jcr:e42483e4-4087-3544-a6a2-f958427c1030/Elastollan_Properties-Chemical-Properties.pdf) (accessed Feb. 12, 2026).
[3] T. Boissonneault, “Vapor smoothing 3D printed parts.” Wevolver. https://www.wevolver.com/article/vapor-smoothing-3d-printed-parts?utm_source=chatgpt.com (https://www.wevolver.com/article/vapor-smoothing-3d-printed-parts?utm_source=chatgpt.com) (accessed Feb. 12, 2026).
[4] “Understanding different types of USB cables for mobile charging.” GP Batteries. https://uk.gpbatteries.com/
blogs/news/understanding-different-types-of-usb-cables-for-mobile-charging (https://uk.gpbatteries.com/blogs/news/understanding-different-types-of-usb-cables-for-mobile-charging) (accessed Feb. 12, 2026).
[5] S. Wickstrom, “PETG vs PLA vs ABS: 3D Printing Strength Comparison,” Ultimaker. [Online]. Available:
https://ultimaker.com/learn/petg-vs-pla-vs-abs-3d-printing-strength-comparison/. Accessed: Feb. 12, 2026.
[6] The Blind Life, “Making Voice Labels with NFC Tags”, YouTube video, 2025 (approx.). [Online]. Available:
https://www.youtube.com/watch?v=txDQfPz1oOw

DR2

[1] “Understanding different types of USB cables for mobile charging.” Gp Batteries. https://uk.gpbatteries.com/blogs/news/understanding-different-types-of-usb-cables-for-mobile-charging (accessed Feb. 12, 2026).
[2] American Speech-Language-Hearing Association, “Classroom Acoustics,” ASHA Practice Portal. [Online]. Available: https://www.asha.org/practice-portal/professional-issues/classroom-acoustics/[Accessed: Mar. 22, 2026].
[3] S. Parker, “Storing PECS Pictures,” The Autism Helper. [Online]. Available: https://theautismhelper.com/storing-pecs-pictures/
[Accessed: Mar. 22, 2026].

DR3

[1] Y. Suzuki and T. Tanaka, "Vibration and acoustic analysis for the speaker cover," J. Technol. Soc. Sci., vol. 6, no. 2, pp. 112–125, 2022.
[2] E. Fitzgerald, Straight Language for the Deaf: A System of Instruction for Deaf Children, 2nd ed. Washington, DC, USA: The Volta Bureau, 1926.
[3] S. C. Wu, C. L. Lin, and C. Y. Chen, "Effects of color-coded designs on cognitive load and learning performance: An eye-tracking and EEG study," Front. Psychol., vol. 12, art. 642013, Jun. 2021, doi: 10.3389/fpsyg.2021.642013.

Individual Contributions

Table 7: Individual contributions

Name | Contributions | Hours since DR3
Ethan D’Souza | 1. created opportunity statement and key design
| features collage in final paper
2. took photos for final paper
3. Wrote Next Steps paragraph in final paper
4. Formatted and edited problem framing
| documentation throughout semester and formatted
| in final paper
5. updated and formatted testplan in final paper
6. updated and formatted references section in final
| paper
7. Completed Eco-Design Strategies paragraph for
| final paper
8. Completed Broader Impacts section for final paper
a. researched and completed benefits and
| risks/tradeoffs
9. Completed formatting and cleanliness of final
| paper
10. contributed to revision of Poster and completed
| electronics selection

6

Logan Frazer 1. Helped with poster content and formatting

2. Helped with paper content and formatting

6

| 3. Programmed NFC cards with final word set 4. Updated and finalized CAD drawings 5. Updated figures 1-5 6. Annotated main case assembly drawing
Aiden McManis | 1. Helped with Poster with organization, and to make sure everything looked good 2. Gantt Chart put into doc 3. Helped with presentation for Design Showcase | 4
Owen Willoby | 1. Created the Poster and worked to finalize it 2. Kept and organized all receipts and finalized the budget 3. Helped with presentation for design showcase 4. Helped troubleshoot product and fix product 5. Helped with paper content and formatting | 5
Jeremiah Koenig | 1. Helped finish product (clean up all parts, put final components on PCB, assemble final product) 2. Helped touch up poster 3. Helped work on presentation | 10
Collin Snider | 1. PCB diagnosing and repair 2. Install new board 3. Helped with poster design 4. Helped with final paper 5. Helped to assemble and clean up wiring of electronics in the final product | 25

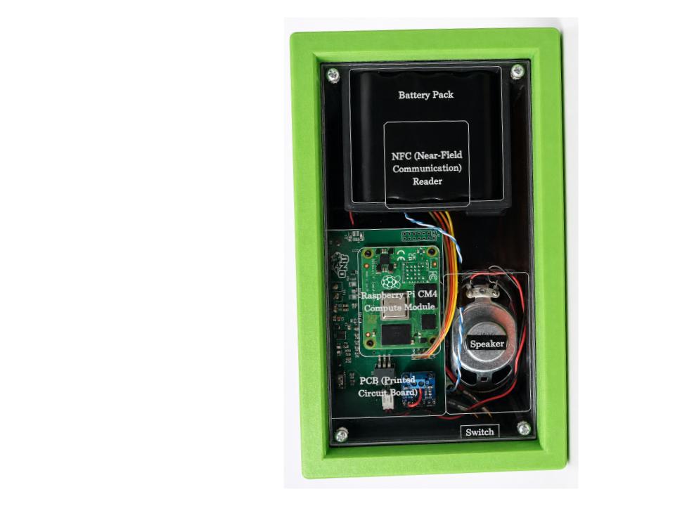
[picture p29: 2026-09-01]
Final Documentation/Electronic Annotation.jpg

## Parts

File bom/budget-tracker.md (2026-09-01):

# Appendix 4: Budget Tracker

| Item Description | Qty Purchased | Vendor/Source | Cost |
|---|---|---|---|
| NFC Cards | 20 | Amazon | $8.99 |
| Batteries | 1 | Batteries.net | $38.39 |
| 3D Printing Filament | — | Donated | Donated |
| PCB | 5 | JLCPCB | $22.79 |
| NFC Card Reader | 1 (2-pack) | Amazon | $12.99 |
| 10 µF ±10% 16V Ceramic Capacitor | 2 | DigiKey | $0.20 |
| 22 µF ±20% 10V Ceramic Capacitor | 2 | DigiKey | $0.42 |
| 0.047 µF ±10% 50V Ceramic Capacitor | 1 | DigiKey | $0.10 |
| 100-Position Connector Receptacle, Center Strip Contacts | 4 | DigiKey | $7.56 |
| Connector Header Through Hole, Right Angle 2-position | 2 | DigiKey | $0.22 |
| USB-C Charging Port | 1 | DigiKey | $0.52 |
| 1 µH Shielded Molded Inductor, 3.2A, 50mΩ Max, 0805 | 1 | DigiKey | $0.23 |
| Red LED Indicator | 3 | DigiKey | $0.36 |
| Green LED Indicator | 1 | DigiKey | $0.12 |
| Lithium-Ion / Polymer Charger | 1 | DigiKey | $3.12 |
| Buffer, Non-Inverting, 1 Element, 1 Bit/Element, Open Drain | 1 | DigiKey | $0.10 |
| Linear Voltage Regulator IC, Positive Fixed, 1 Output, 5A, TO-263 | 1 | DigiKey | $2.97 |
| Raspberry Pi Compute Module 4 | 1 | DigiKey | $35.00 |
| Raspberry Pi CM4 IO Board | 1 | DigiKey | $35.00 |
| 1-Channel (Mono) Output Class-D Audio Amplifier Eval Board | 1 | DigiKey | $5.95 |
| Speaker | 1 | DigiKey | $5.23 |
| Tax and Shipping (DigiKey order) | 1 | — | $15.84 |
| Tax and Shipping (Amazon order) | 1 | — | $1.59 |
| Audio Amp | 1 (2-pack) | Amazon | $7.38 |

**Expected total budget spent:** $205.07
**Expected budget remaining:** $4.93

> Vendor links preserved from the original team budget tracker (Amazon, Batteries.net, JLCPCB, DigiKey) — swap in your own sourcing links if forking this BOM for a new build.

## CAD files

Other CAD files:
design/Drawer Drawings/Final Iterations/Drawer Drawing.SLDDRW
design/Drawer Drawings/Final Iterations/Opening Drawer Drawing.SLDDRW
design/Drawer Drawings/Final Iterations/Slider Drawing.SLDDRW
design/Drawer Drawings/Final Iterations/Slider Helper Drawing.SLDDRW
design/Main Device Drawings/Bumper Bottom FINAL.SLDDRW
design/Main Device Drawings/Bumper Top FINAL.SLDDRW
design/Main Device Drawings/Case FINAL.SLDDRW
design/Main Device Drawings/Device Assembly FINAL.SLDDRW
design/Main Device Drawings/Do Not Submit_ V1 Iterations/Battery Cover.SLDDRW
design/Main Device Drawings/Do Not Submit_ V1 Iterations/Bumper.SLDDRW
design/Main Device Drawings/Do Not Submit_ V1 Iterations/Case Lid.SLDDRW
design/Main Device Drawings/Do Not Submit_ V1 Iterations/Case.SLDDRW
design/Main Device Drawings/Do Not Submit_ V1 Iterations/Device Assembly.SLDDRW

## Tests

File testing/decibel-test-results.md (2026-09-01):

# Appendix 2: Test Results

**Test Title:** Decibel Output Testing for Variable Speaker Holes

**Purpose:** To determine the best speaker cover to ensure optimal sound clarity and quality, as determined by decibel levels.

## Equipment

- Speaker
- Microcontroller
- Amplifier
- Speaker covers (6 covers)
- Sound level meter
- Tape measure
- Means to record data

## Variables

**Independent:** Speaker hole size
**Control:** Distance between reader and speaker, speaker volume, speaker, material of cover, same word tested
**Dependent:** Sound output level (dB)
**Uncontrollable:** Cleanliness of speaker holes, accuracy of measurement tools

## Experimental Setup

Speaker covers were 3D-printed with varying hole diameters (1.5mm, 2.0mm, 2.5mm, 3.0mm, 3.5mm, 4.0mm). A sound level reader was held at ear level, at a fixed distance (measured with a tape measure) from the speaker, which was oriented toward the reader.

Decibel testing setup with speaker, ESP32, amplifier, and sound level meter

## Procedure

1. Gather all materials.
2. Place materials on a table that is cleared and ready for the test.
3. Hook up the speaker to the amplifier + microcontroller apparatus.
4. Cover speaker with speaker cover.
5. Hold sound level reader at ear level (speaker oriented toward reader, still on the table).
6. Use the sound level reader to collect data from the speaker output.
7. Output a text-to-speech word from the speaker.
8. Repeat steps 4–6, changing/adding the speaker cover for each hole diameter.
9. Record results in the data table.
10. Record any observations.

## Quantitative Results

Raw dB readings per test phrase, per hole diameter:

| Phrase | Control (no cover) | 1.5mm | 2.0mm | 2.5mm | 3.0mm | 3.5mm | 4.0mm |
|---|---|---|---|---|---|---|---|
| "Why" | 66.5 | 72.4 | 75.6 | 76.5 | 76.3 | 63.7 | 68.8 |
| "Please" | 70.4 | 64.3 | 65.8 | 65.7 | 68.5 | 70.3 | 72.6 |
| "Stop" | 68.6 | 58.0 | 59.4 | 72.9 | 57.3 | 75.6 | 63.1 |
| **Average** | **68.5** | **64.9** | **66.9** | **71.7** | **67.4** | **69.9** | **68.2** |

## Observations

After conducting the experiment, the team found the **2.5mm diameter speaker grille** gave the best average sound output. It also did better at keeping out dust and debris than its larger counterparts. Smaller diameters had too much sound loss to justify their improved debris resistance — so 2.5mm was selected as the best overall balance between clarity and durability.

**Conducted by:** Ethan D'souza, Owen Willoby, Jeremiah Koenig, Aiden McManis
**Date tested:** 4/9/26

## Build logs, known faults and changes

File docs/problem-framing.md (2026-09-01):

# Appendix 1: Problem Framing

**Overview:** Problem Framing Documentation for FoD2 Semester Project "Word Wizard"

## Broader Impacts (Summary)

1. **People** — Inclusion and accessibility, reducing stigma around disability.
2. **Planet** — A long-lasting, purpose-built solution allows for less material waste and power consumption.
3. **Profit** — Lower cost and a scalable solution compared to existing assistive technologies.

## Stakeholders

| Stakeholder | Impact | Design Decision Considerations |
|---|---|---|
| Student | Usability, comfort, reliability | Safer casing, minimal simplistic inputs |
| Teachers | Integration and manageability | Small, rechargeable, minimal design, clear colors for locatability |
| Administrators | Budget and policy compliance | Low-tech design, cost less than common alternatives (tablet or repurposed smart device) |
| Parents | Independence and safety | Soft outer casing, simplistic usability for a wide age range |

## Preliminary Research

### Design Round 1 (DR1)

| # | Prompting Question | Source | Info Gathered | Use of Info |
|---|---|---|---|---|
| 1 | How tall are classroom desks and tables? | Dimensions.com | 24"–30" | Informs durability/drop benchmarks |
| 2 | How can we smooth 3D prints? | [Wevolver, BASF] | ABS can be smoothed with acetone, TPU with DMSO | Consider solvent smoothing for surface finish |
| 3 | What is the most common consumer charging cable? | GP Batteries | USB-C is the modern industry standard | Use a USB-C port for power input |
| 4 | What 3D printing filament is most durable? | Ultimaker | ABS has higher impact resistance than PLA/PETG but worse printability | ABS preferred for strength; print carefully |
| 5 | Why use NFC tags instead of alternatives for voice recording? | The Blind Life (YouTube) | NFC offers easy, touch-based playback/recording/updating of audio | Use NFC tags for easy, low-complexity use and updating |
| 6 | What are the issues with paper communication cards? | Christina Teevan, Ashland Special Needs Ministry | Paper cards are not durable, difficult to organize, and require concentration from both parties | Combine physical cards with a text-to-speech device |

### Design Round 2 (DR2)

| # | Prompting Question | Source | Info Gathered | Use of Info |
|---|---|---|---|---|
| 1 | What's an effective dB level for communication, and how does enclosure design affect it? | ASHA Classroom Acoustics | Target output 60–65 dB at listener; upper range 65–70 dB in noisy classrooms | Aim for 60–65 dB output range |
| 2 | How do educators currently store/organize communication cards? | The Autism Helper | Bins and binder pockets are common storage methods | Blend both systems into an organized drawer |

### Design Round 3 (DR3)

| # | Prompting Question | Source | Info Gathered | Use of Info |
|---|---|---|---|---|
| 1 | How can we reduce speaker rattle in the enclosure? | Suzuki & Tanaka, J. Technol. Soc. Sci. | Sealing between speaker and surface dictates sound pressure level | Add a gasket to seal the speaker |
| 2 | How can we further make cards easier to organize? | Fitzgerald (1926); Wu et al., Front. Psychol. 2021 | AAC systems use the Fitzgerald Key to color-code grammatical categories; color coding reduces cognitive load | Color-code the cards for organization and tracking |

## Assumptions

1. Classroom desks/tables are typically 24"–30" tall, so accidental drops of ~3 ft onto hard flooring are likely — the enclosure is designed to withstand at least a 3 ft drop without functional failure.
2. Some non-verbal individuals may also have visual processing challenges, so high-contrast visual cues (colors, iconography) improve usability.
3. In classrooms with many simultaneous interactable objects, cards may be frequently misplaced — a dedicated card storage/tethering solution was integrated.
4. Hygiene practices in schools/therapy settings require frequent surface cleaning — enclosure materials (ABS/TPU/PLA) were selected to tolerate repeated wiping.
5. USB-C cables are commonly included with consumer electronics and are easily purchasable, so a USB-C port was used for power input.

## Design Specifications

| # | Evaluation Metric | Qty. to Measure | Units | Objective | Approach |
|---|---|---|---|---|---|
| 1 | Battery Life | Both | Watt-hour (Wh) | ≥ 30 Wh | Rechargeable battery with safety margin |
| 2 | Boot Time | EM | Seconds (s) | Minimize | Optimize hardware using a compute module |
| 3 | Response Time | EM | Seconds (s) | Minimize | Optimize hardware using a compute module |
| 4 | Sound Level | EM | Decibels (dB) | ≥ 60 dB | Functionally test different speaker grilles |
| 5 | Portability | EM | Grams (g) | Minimize | Minimize unnecessary cables/hardware |
| 6 | Variability of Word List | C | # of cards | ≥ 30 | Diversified vocabulary for versatility |
| 7 | Customizability of Word List | EM | # of ways to change each card | Maximize | Cards changeable on demand via smartphone |

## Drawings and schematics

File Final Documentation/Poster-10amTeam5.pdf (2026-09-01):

# Word Wizard

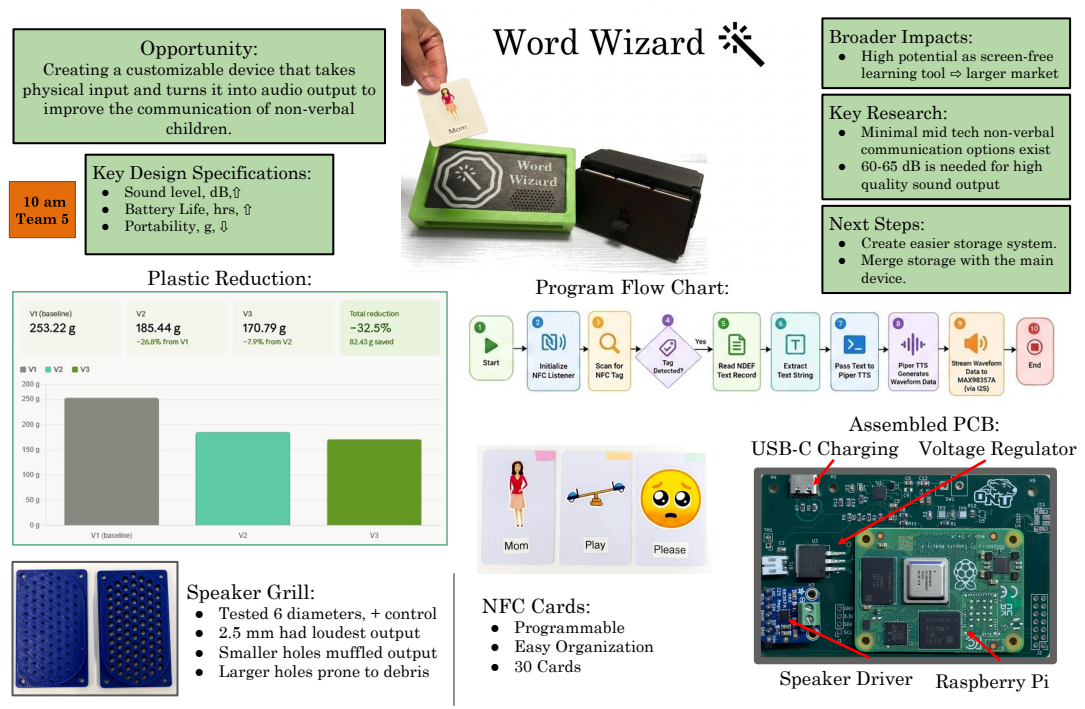
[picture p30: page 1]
Opportunity:; children.; Assembled PCB:; ● Larger holes prone to debris; Raspberry Pi; NFC Cards: ● Programmable ● Easy Organization ● 30 Cards; Speaker Driver

Broader Impacts:
● High potential as screen-free
learning tool ⇨ larger market

Creating a customizable device that takes
physical input and turns it into audio output to
improve the communication of non-verbal

Key Research:
● Minimal mid tech non-verbal
communication options exist
● 60-65 dB is needed for high
quality sound output

Key Design Specifications:
● Sound level, dB,⇧
● Battery Life, hrs, ⇧
● Portability, g, ⇩

Next Steps:
● Create easier storage system.
● Merge storage with the main
device.

Program Flow Chart: Plastic Reduction:

USB-C Charging Voltage Regulator

Speaker Grill:
● Tested 6 diameters, + control
● 2.5 mm had loudest output
● Smaller holes muffled output

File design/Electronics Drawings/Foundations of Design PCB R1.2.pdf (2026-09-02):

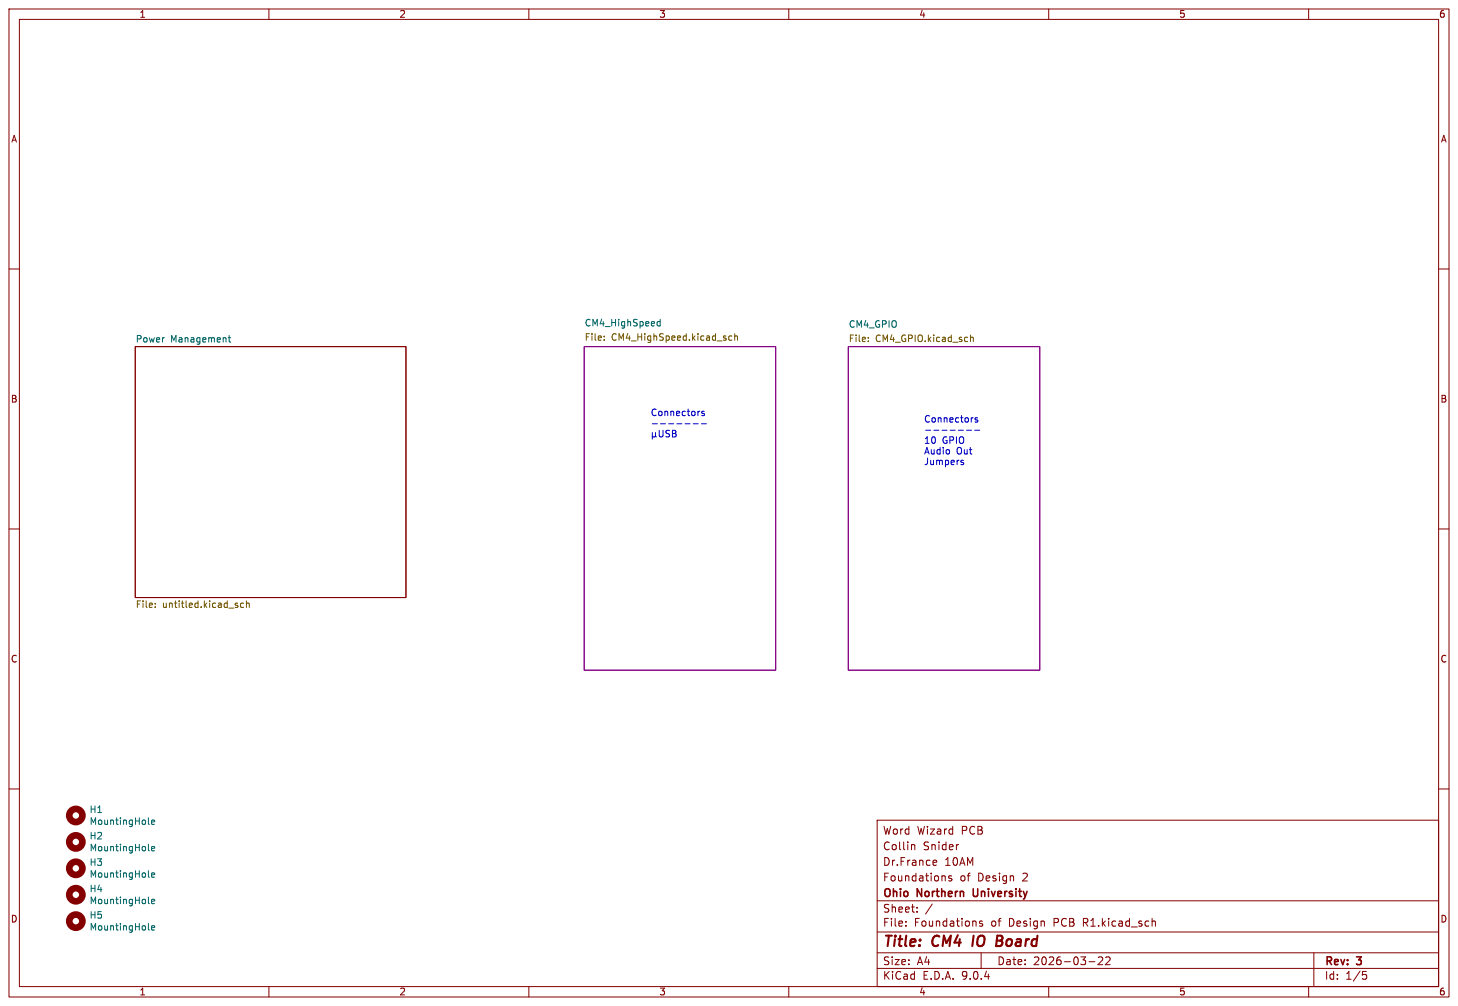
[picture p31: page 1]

File: CM4_GPIO.kicad_sch H2 MountingHole H5 MountingHole H3 MountingHole H1 MountingHole H4 MountingHole

Id: 1/5 Title: CM4 IO Board

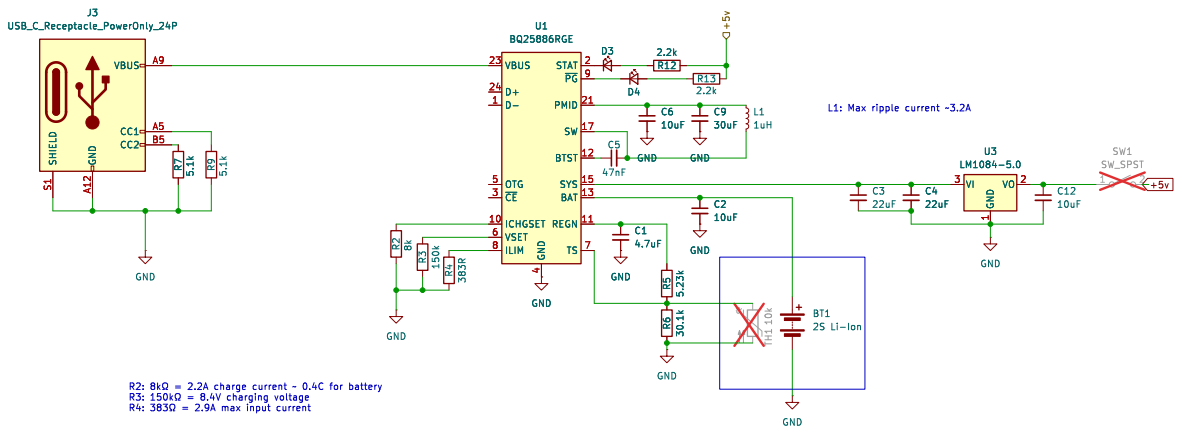
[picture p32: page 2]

4 STAT 2 ~{PG}9 PMID 21 SW 17 BTST 12 SYS 15 BAT 13 REGN 11 TS 7 U1 BQ25886RGE R3 150k GND

4 STAT 2 ~{PG}9 PMID 21 SW 17 BTST 12 SYS 15 BAT 13 REGN 11 TS 7 D3 GND
2.2k GND

Id: 4/5 Title: CM4 IO Board

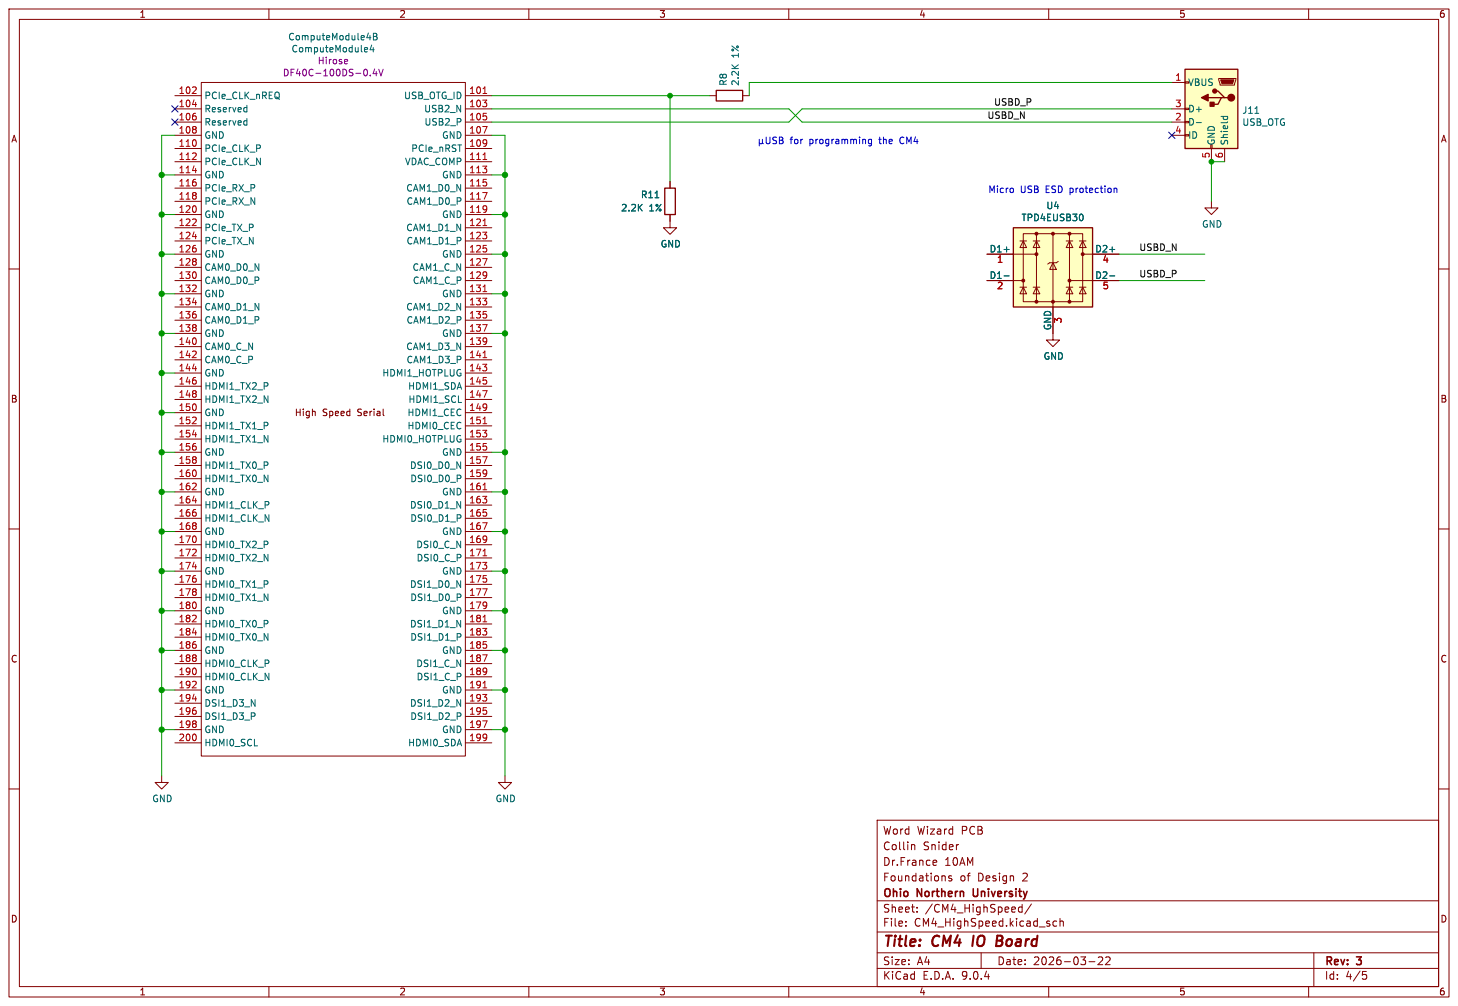
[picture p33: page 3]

USBD_P Micro USB ESD protection

Id: 4/5 Title: CM4 IO Board

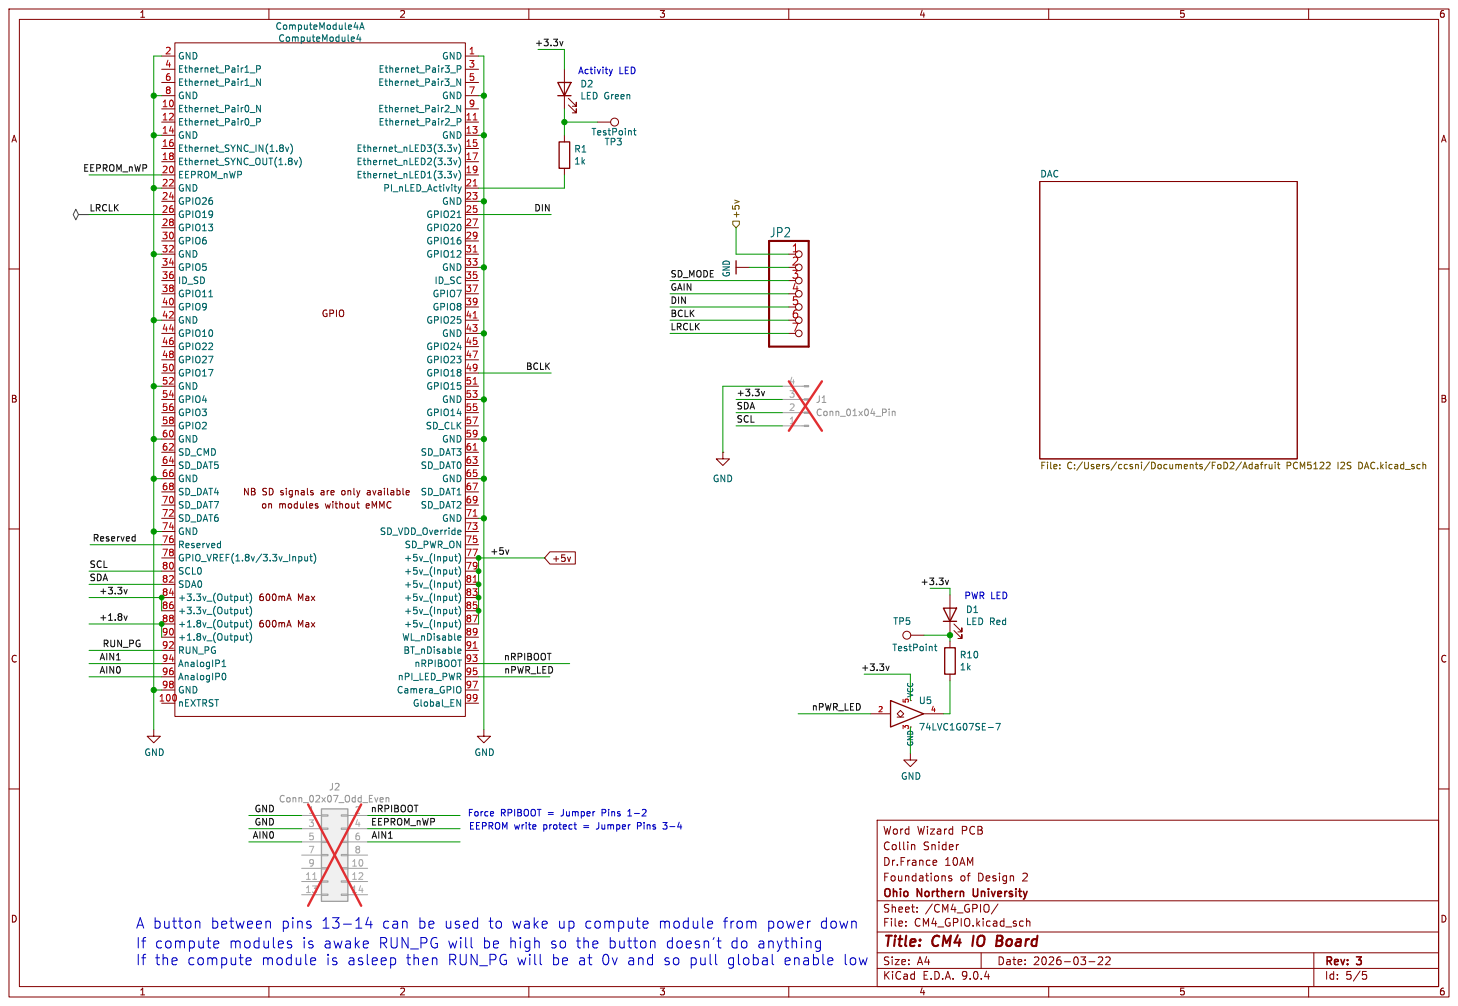
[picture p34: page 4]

on modules without eMMC GPIO

1k 600mA Max 600mA Max NB SD signals are only available

Force RPIBOOT = Jumper Pins 1-2

Id: 5/5 Title: CM4 IO Board

If compute modules is awake RUN_PG will be high so the button doesn't do anything
If the compute module is asleep then RUN_PG will be at 0v and so pull global enable low

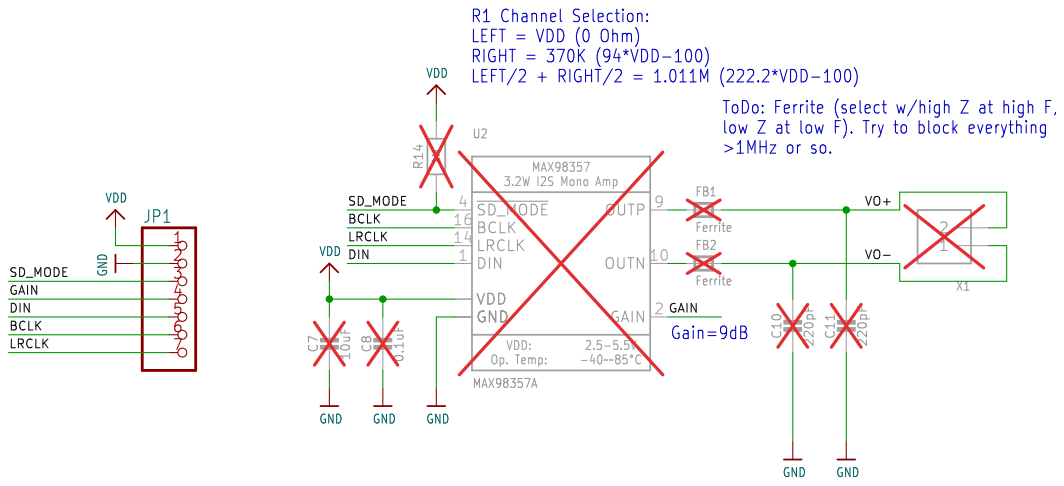
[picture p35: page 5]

Id: 5/5 Title: CM4 IO Board

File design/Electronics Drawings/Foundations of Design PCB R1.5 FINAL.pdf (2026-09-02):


------- Micro USB Connectors
------- USB Tpye-C Power Only

I2S Audio Boot Jumpers Connectors

Id: 1/5 Title: CM4 IO Board

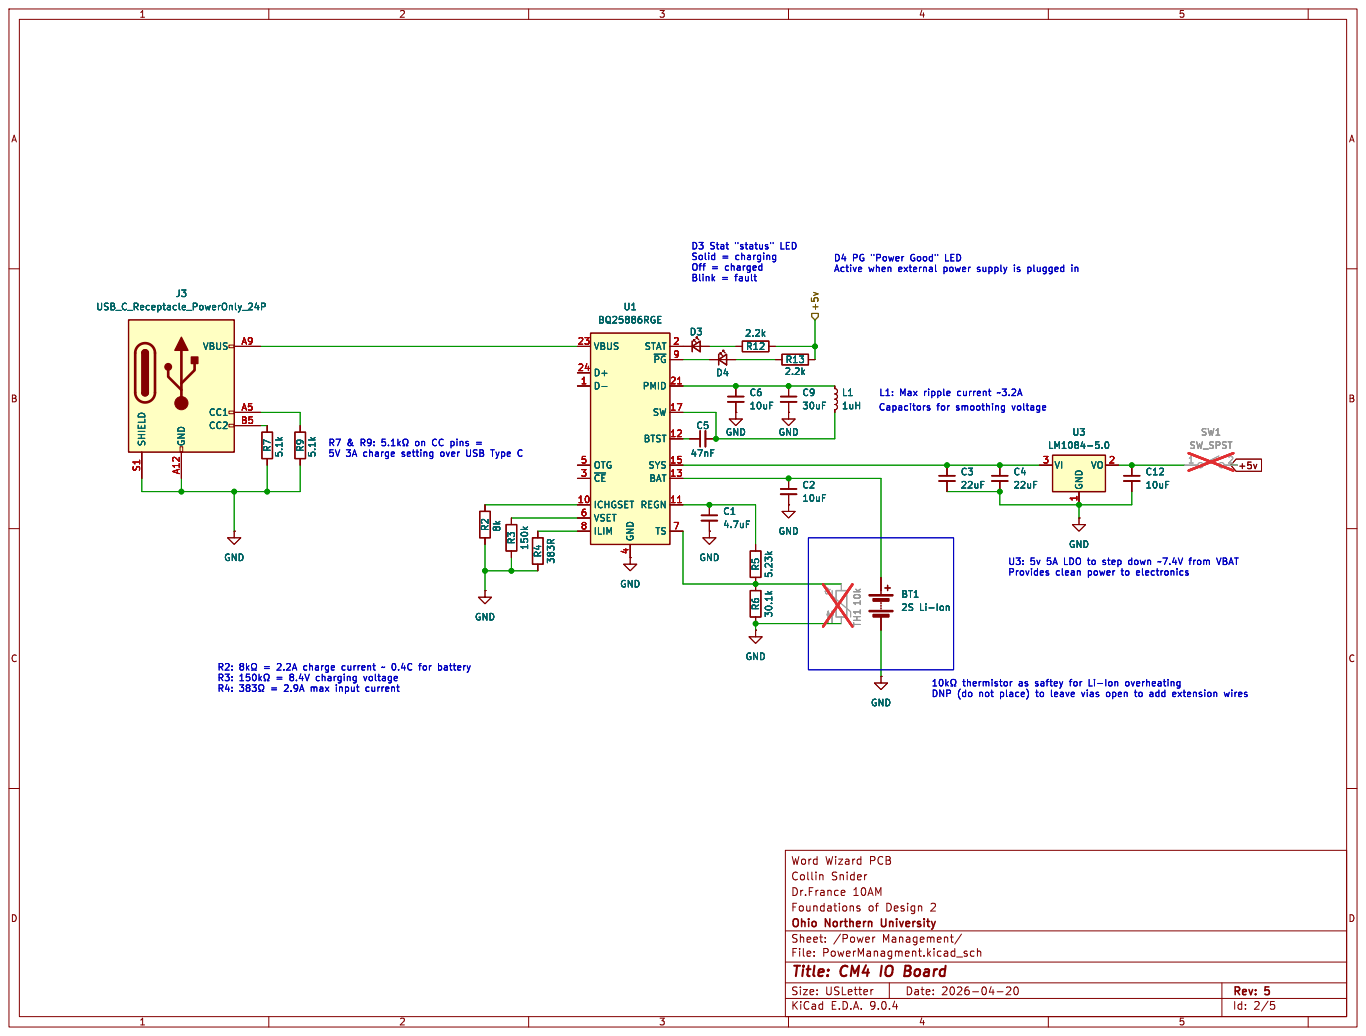
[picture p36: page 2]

Solid = charging Off = charged Blink = fault R7 & R9: þÿ5.1k©on CC pins =

4 STAT 2 ~{PG}9 PMID 21 SW 17 BTST 12 SYS 15 BAT 13 REGN 11 TS 7 U1 BQ25886RGE GND GND R7 5.1k GND R4 383R SHIELD S1 GND A12 VBUS A9 CC1 A5 CC2 B5

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

4 STAT 2 ~{PG}9 PMID 21 SW 17 BTST 12 SYS 15 BAT 13 REGN 11 TS 7 GND GND

5V 3A charge setting over USB Type C

R7 & R9: þÿ5.1k©on CC pins =

Id: 2/5 Title: CM4 IO Board


Id: 3/5 Title: CM4 IO Board

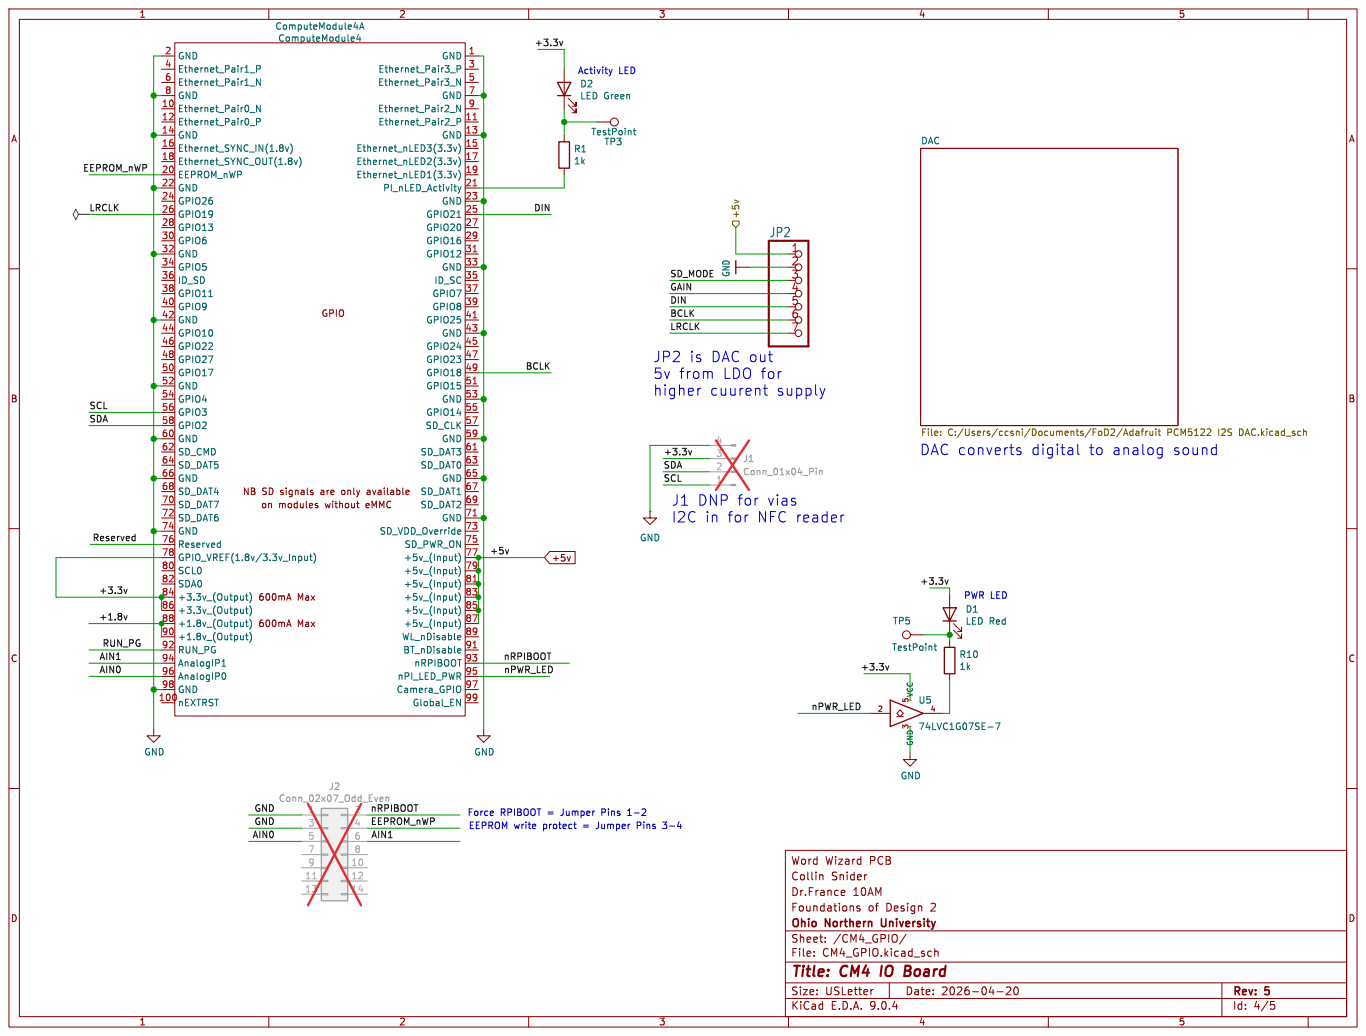
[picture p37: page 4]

on modules without eMMC GPIO

600mA Max 600mA Max NB SD signals are only available

I2C in for NFC reader EEPROM write protect = Jumper Pins 3-4

Id: 4/5 Title: CM4 IO Board


Id: 5/5 Title: CM4 IO Board

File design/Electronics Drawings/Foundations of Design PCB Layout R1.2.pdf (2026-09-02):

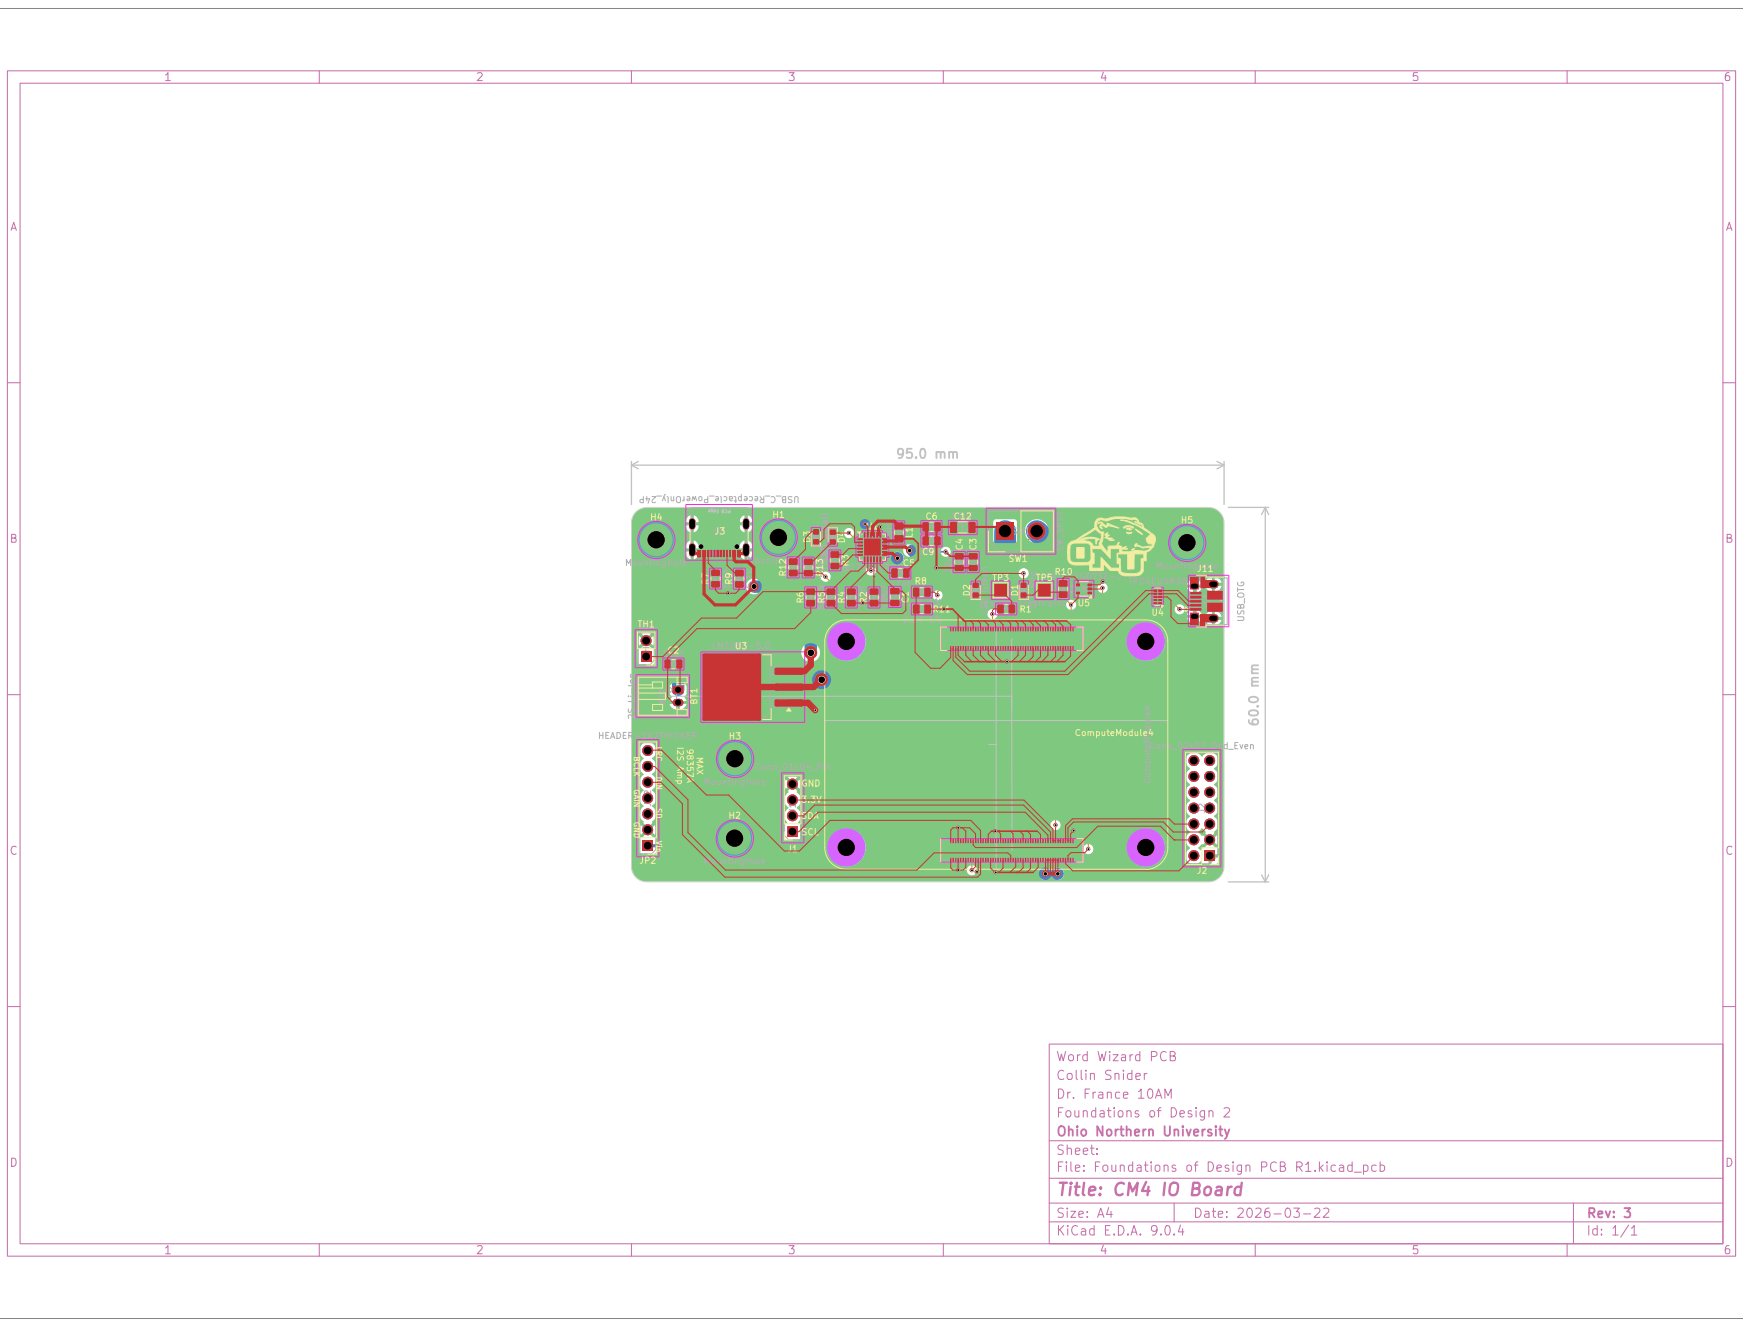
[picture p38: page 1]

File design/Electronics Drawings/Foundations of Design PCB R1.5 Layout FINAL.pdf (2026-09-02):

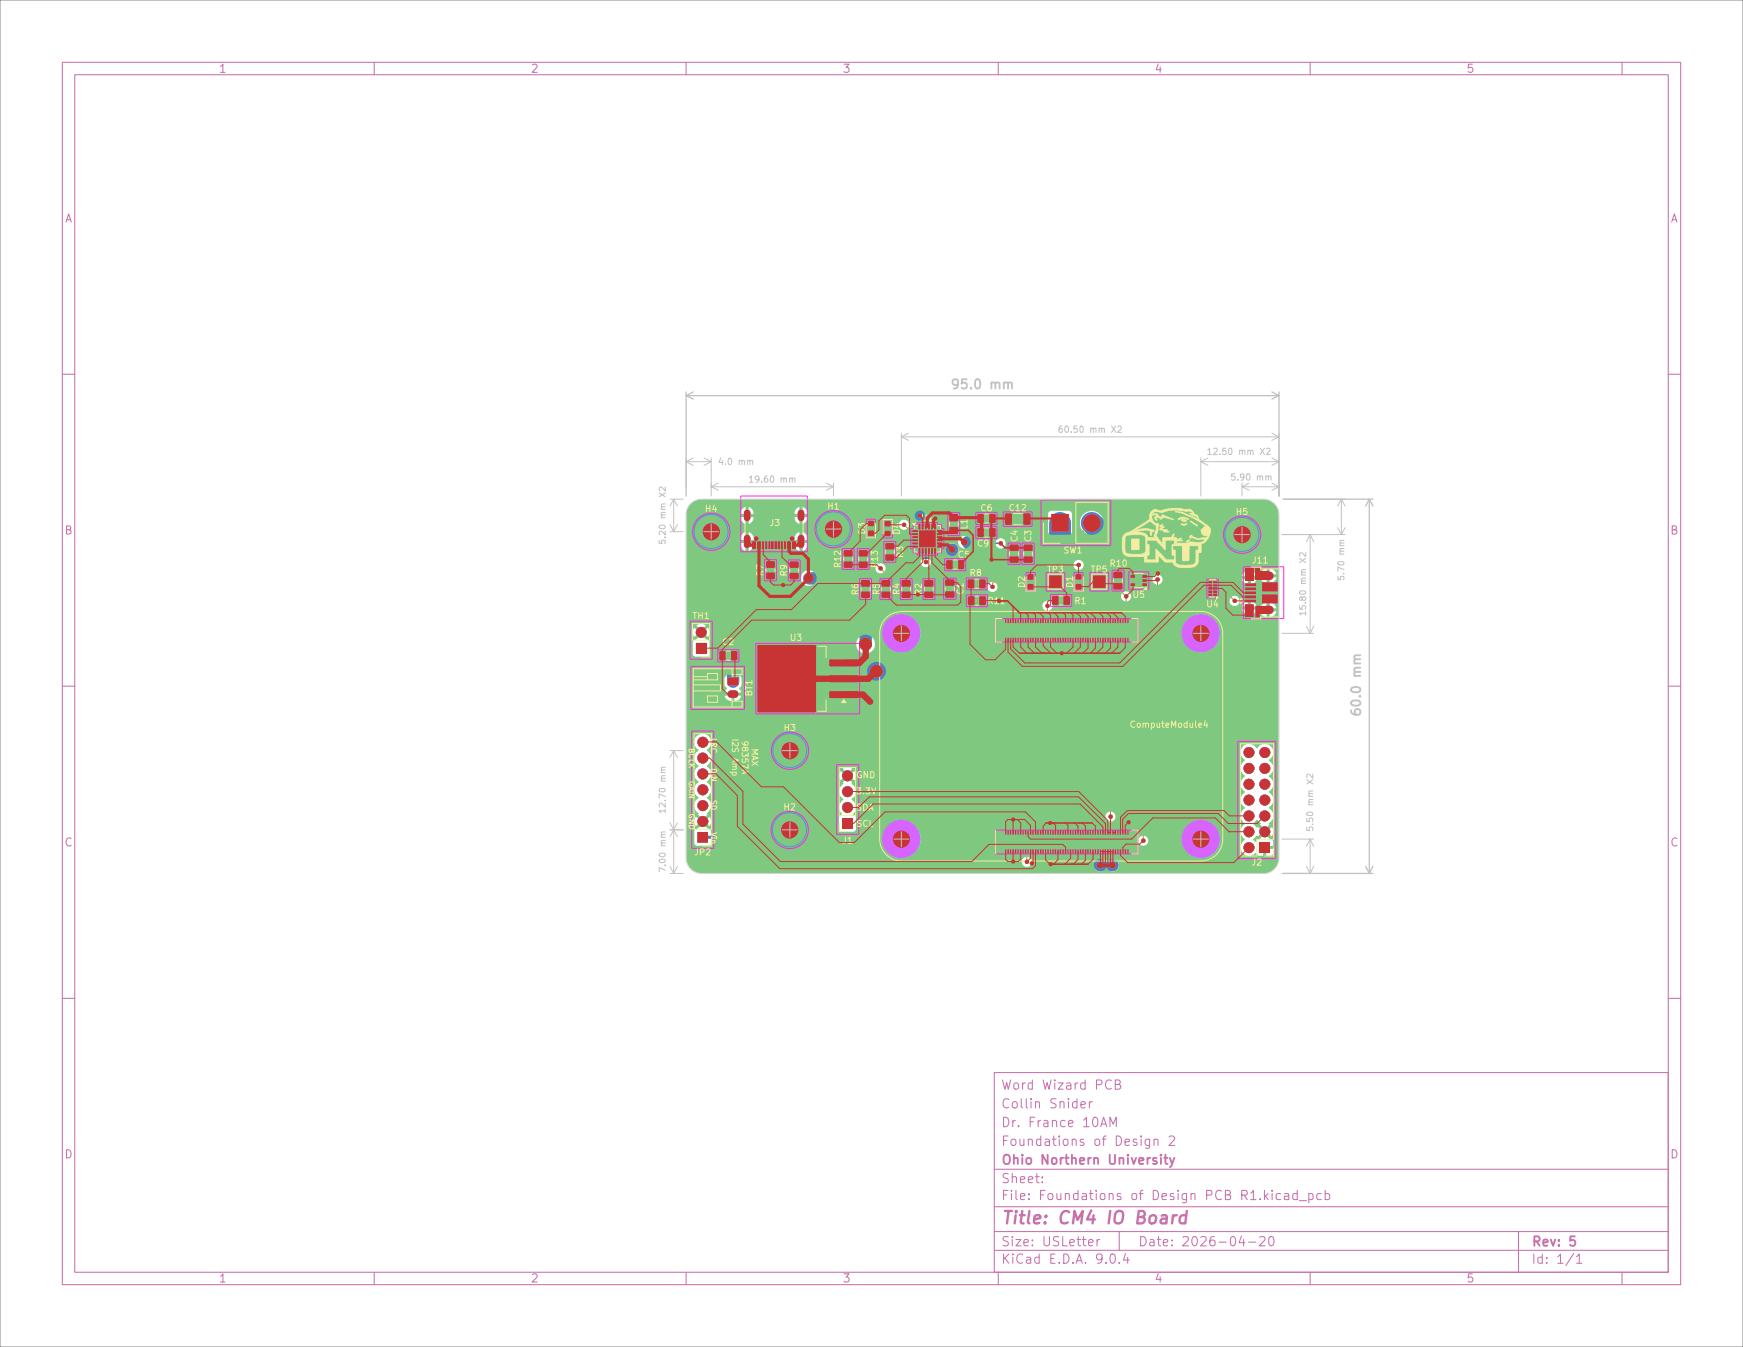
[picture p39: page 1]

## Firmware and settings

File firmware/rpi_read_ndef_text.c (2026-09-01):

/**
 * Python script to read NFC card and push text data to Piper TTS
 * rpi_read_ndef_text.c
 *
 * Reads NDEF Text records from NFC cards (NTAG2xx / Mifare Ultralight)
 * using the pn532-lib on Raspberry Pi.
 *
 * Based on: https://github.com/soonuse/pn532-lib/blob/master/examples/raspberrypi/rpi_dump_ntag2.c
 *
 * Build:
 *   gcc -o rpi_read_ndef_text rpi_read_ndef_text.c -lpn532 -lpn532_rpi
 *
 * Wiring (I2C, default):
 *   PN532 SDA -> RPi GPIO 2 (Pin 3)
 *   PN532 SCL -> RPi GPIO 3 (Pin 5)
 *   PN532 VCC -> 3.3V or 5V
 *   PN532 GND -> GND
 */

#include <stdio.h>
#include <stdint.h>
#include <string.h>
#include "pn532.h"
#include "pn532_rpi.h"

/* ── NTAG2xx layout ──────────────────────────────────────────────────────────
 * Block 0-3   : UID / lock bytes / capability container
 * Block 4+    : user data (TLV-encoded NDEF messages)
 * Last blocks : dynamic lock / CFG (tag-size dependent)
 *
 * Each block is 4 bytes; total user blocks vary by tag variant:
 *   NTAG213 -> blocks 4-39   (144 bytes)
 *   NTAG215 -> blocks 4-129  (496 bytes)
 *   NTAG216 -> blocks 4-225  (888 bytes)
 * We read up to block 135 (same ceiling as the dump example).
 * ─────────────────────────────────────────────────────────────────────────── */

#define MAX_BLOCKS       135
#define BLOCK_SIZE       4
#define USER_START_BLOCK 4      /* first data block */

/* TLV tags */
#define TLV_NULL         0x00
#define TLV_NDEF         0x03
#define TLV_TERMINATOR   0xFE

/* NDEF TNF (Type Name Format) mask */
#define NDEF_TNF_MASK        0x07
#define NDEF_TNF_WELL_KNOWN  0x01

/* NDEF flags */
#define NDEF_FLAG_MB  0x80  /* Message Begin */
#define NDEF_FLAG_ME  0x40  /* Message End */
#define NDEF_FLAG_SR  0x10  /* Short Record */

/* NDEF Well-Known Type: "T" = Text */
#define NDEF_TYPE_TEXT 'T'

/* ── Helper: print raw hex bytes ─────────────────────────────────────────── */
static void print_hex(const uint8_t *data, size_t len)
{
    for (size_t i = 0; i < len; i++) {
        printf("%02X ", data[i]);
    }
    printf("\n");
}

/* ── Parse and print one NDEF Text record payload ────────────────────────── */
/*
 * Text record payload format (RFC 5646):
 *   Byte 0       : status byte - bit7=UTF16, bits5-0=lang length
 *   Bytes 1..L   : language code (e.g. "en")
 *   Bytes L+1..N : text (UTF-8 or UTF-16)
 */
static void parse_ndef_text(const uint8_t *payload, uint32_t payload_len)
{
    if (payload_len < 1) {
        printf("[!] Payload too short\n");
        return;
    }

    uint8_t status   = payload[0];
    uint8_t lang_len = status & 0x3F;      /* lower 6 bits */
    int is_utf16     = (status & 0x80) != 0;

    if ((uint32_t)(1 + lang_len) >= payload_len) {
        printf("[!] Malformed Text record\n");
        return;
    }

    /* Language code */
    char lang[64] = {0};
    memcpy(lang, payload + 1, lang_len);

    /* Text content */
    const uint8_t *text = payload + 1 + lang_len;
    uint32_t text_len   = payload_len - 1 - lang_len;

    printf("Encoding: %s\n", is_utf16 ? "UTF-16" : "UTF-8");
    printf("Language: %s\n", lang);
    printf("Text: ");

    if (is_utf16) {
        /* Naive UTF-16LE print - strips high byte */
        for (uint32_t i = 0; i + 1 < text_len; i += 2) {
            putchar(text[i]);
        }
    } else {
        /* UTF-8: just print as-is (terminal must support UTF-8) */
        for (uint32_t i = 0; i < text_len; i++) {
            putchar(text[i]);
        }
    }
    putchar('\n');
}

/* ── Walk the TLV stream in the user-data buffer ────────────────────────── */
static void parse_ndef_tlv(const uint8_t *data, size_t data_len)
{
    size_t pos = 0;
    int found_any = 0;

    while (pos < data_len) {
        uint8_t tag = data[pos++];

        if (tag == TLV_NULL) { continue; }
        if (tag == TLV_TERMINATOR) { break; }

        if (pos >= data_len) break;

        /* TLV length - extended (3-byte) form if 0xFF */
        uint32_t length;
        if (data[pos] == 0xFF) {
            if (pos + 2 >= data_len) break;
            length = ((uint32_t)data[pos + 1] << 8) | data[pos + 2];
            pos += 3;
        } else {
            length = data[pos++];
        }

        if (pos + length > data_len) {
            printf("[!] TLV value exceeds buffer - tag 0x%02X, len %u\n",
                   tag, length);
            break;
        }

        if (tag != TLV_NDEF) {
            pos += length; /* skip unknown TLV */
            continue;
        }

        /* ── Found an NDEF message TLV ─────────────────────────── */
        const uint8_t *ndef_msg = data + pos;
        size_t ndef_remain = length;
        pos += length;

        /* Walk individual NDEF records inside the message */
        size_t rpos = 0;
        while (rpos < ndef_remain) {
            if (rpos + 3 > ndef_remain) break;

            uint8_t flags    = ndef_msg[rpos++];
            uint8_t type_len = ndef_msg[rpos++];

            /* Payload length: SR flag -> 1 byte, else 4 bytes */
            uint32_t payload_len;
            if (flags & NDEF_FLAG_SR) {
                if (rpos >= ndef_remain) break;
                payload_len = ndef_msg[rpos++];
            } else {
                if (rpos + 4 > ndef_remain) break;
                payload_len = ((uint32_t)ndef_msg[rpos    ] << 24) |
                              ((uint32_t)ndef_msg[rpos + 1] << 16) |
                              ((uint32_t)ndef_msg[rpos + 2] << 8)  |
                              (uint32_t)ndef_msg[rpos + 3];
                rpos += 4;
            }

            /* ID length (if IL flag set) */
            uint8_t id_len = 0;
            if (flags & 0x08) { /* IL flag */
                if (rpos >= ndef_remain) break;
                id_len = ndef_msg[rpos++];
            }

            if (rpos + type_len + id_len + payload_len > ndef_remain) break;

            const uint8_t *type = ndef_msg + rpos; rpos += type_len;
            /* skip ID */ rpos += id_len;
            const uint8_t *payload = ndef_msg + rpos; rpos += payload_len;

            uint8_t tnf = flags & NDEF_TNF_MASK;

            printf("\n[NDEF Record]\n");
            printf("  TNF  : 0x%02X (%s)\n", tnf,
                   tnf == NDEF_TNF_WELL_KNOWN ? "Well-Known" : "other");

            if (type_len > 0) {
                printf("  Type : %c\n", type[0]);
            }

            if (tnf == NDEF_TNF_WELL_KNOWN &&
                type_len == 1 && type[0] == NDEF_TYPE_TEXT) {
                parse_ndef_text(payload, payload_len);
                found_any = 1;
            } else {
                printf("  Payload : ");
                print_hex(payload, payload_len);
            }

            if (flags & NDEF_FLAG_ME) break; /* last record in message */
        }
    }

    if (!found_any) {
        printf("[i] No NDEF Text records found on this card.\n");
    }
}

/* ── main ────────────────────────────────────────────────────────────────── */
int main(void)
{
    uint8_t block_buf[BLOCK_SIZE];
    uint8_t uid[MIFARE_UID_MAX_LENGTH];
    uint8_t user_data[MAX_BLOCKS * BLOCK_SIZE];
    uint32_t user_data_len = 0;

    printf("=== PN532 NDEF Text Reader ===\n\n");

    PN532 pn532;
    /* Choose ONE init method to match your hardware wiring: */
    PN532_I2C_Init(&pn532);
    /* PN532_SPI_Init(&pn532); */
    /* PN532_UART_Init(&pn532); */

    uint8_t fw[4];
    if (PN532_GetFirmwareVersion(&pn532, fw) != PN532_STATUS_OK) {
        fprintf(stderr, "[!] PN532 not found. Check wiring.\n");
        return -1;
    }
    printf("[+] PN532 detected - firmware v%d.%d\n\n", fw[1], fw[2]);

    PN532_SamConfiguration(&pn532);

    printf("Waiting for NFC card...\n");

    /* ── Poll until a card is presented ──────────────────────────────── */
    int32_t uid_len;
    while (1) {
        uid_len = PN532_ReadPassiveTarget(&pn532, uid,
                                           PN532_MIFARE_ISO14443A, 1000);
        if (uid_len != PN532_STATUS_ERROR) break;
        printf(".");
        fflush(stdout);
    }

    printf("\n[+] Card detected!\n");
    printf("    UID: ");
    for (int32_t i = 0; i < uid_len; i++) {
        printf("%02X ", uid[i]);
    }
    printf("(%d bytes)\n\n", uid_len);

    /* ── Read user data blocks ───────────────────────────────────────── */
    printf("Reading data blocks...\n");
    for (uint8_t blk = USER_START_BLOCK; blk < MAX_BLOCKS; blk++) {
        uint32_t err = PN532_Ntag2xxReadBlock(&pn532, block_buf, blk);
        if (err != PN532_ERROR_NONE) {
            /* End of readable area (e.g. hit config pages) */
            break;
        }
        memcpy(user_data + user_data_len, block_buf, BLOCK_SIZE);
        user_data_len += BLOCK_SIZE;
    }

    printf("[+] Read %u bytes of user data.\n\n", user_data_len);

    /* ── Parse TLV / NDEF ────────────────────────────────────────────── */
    printf("Parsing NDEF records...\n");
    parse_ndef_tlv(user_data, user_data_len);

    printf("\nDone.\n");
    return 0;
}
